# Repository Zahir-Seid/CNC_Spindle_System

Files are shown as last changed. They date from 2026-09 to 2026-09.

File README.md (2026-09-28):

# Design, Analysis and Modeling of CNC Spindle System

Internship project by Group 6, Department of Electromechanical Engineering, AASTU. Host: Ethio-Engineering Group, July–September 2026.

Full report: `Design, Analysis and Modeling of CNC Spindle System.pdf` (source: `.tex`).

## What this project is

Design and system-level model of a BT30 pneumatic tool-change CNC milling spindle rated to 5000 RPM, treated as one integrated mechatronic system: mechanics + motor/drive + PID speed control + PLC supervisory interlock.

Design basis: aluminum 6061-T6 roughing cut with 10 mm 3-flute end mill. Peak cutting force 135 N, peak torque 0.675 N·m, average cutting power ~169 W.

## How it was done

**1. Mechanical design (SolidWorks + hand calcs).**
Shaft, 6004 deep-groove bearings, 7075-T6 housing, BT30-ER20-70 interface, Belleville stack, M12 drawbar, 50:30 5M belt drive, floating puller assembly. Overhung-load model: front bearing 471 N, rear bearing 336 N reversed, max bending moment 16.72 N·m at front bearing.

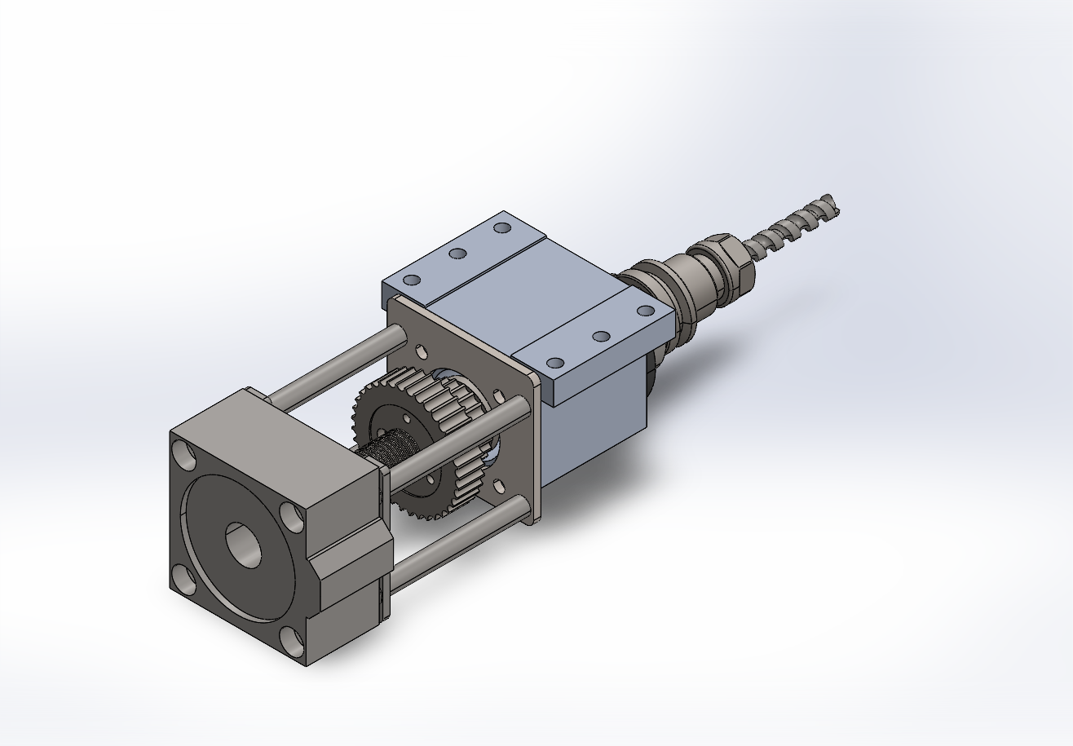
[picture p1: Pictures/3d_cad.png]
CAD assembly


**2. Structural validation (analytical + beam FEA).**
Hollow shaft (20 mm OD / 13 mm ID, 20CrMnTi): von Mises 25.9 MPa, FoS ~28.3. Hand calc and beam FEA agree to 0.1%. Housing shoulder FoS 12–17, puller plate FoS 2.5–3.5. Key finding: shaft is stiffness/bearing-fit governed, not strength governed. Drawbar release load (2940–4021 N) routes through puller plate into housing, bearings stay isolated.

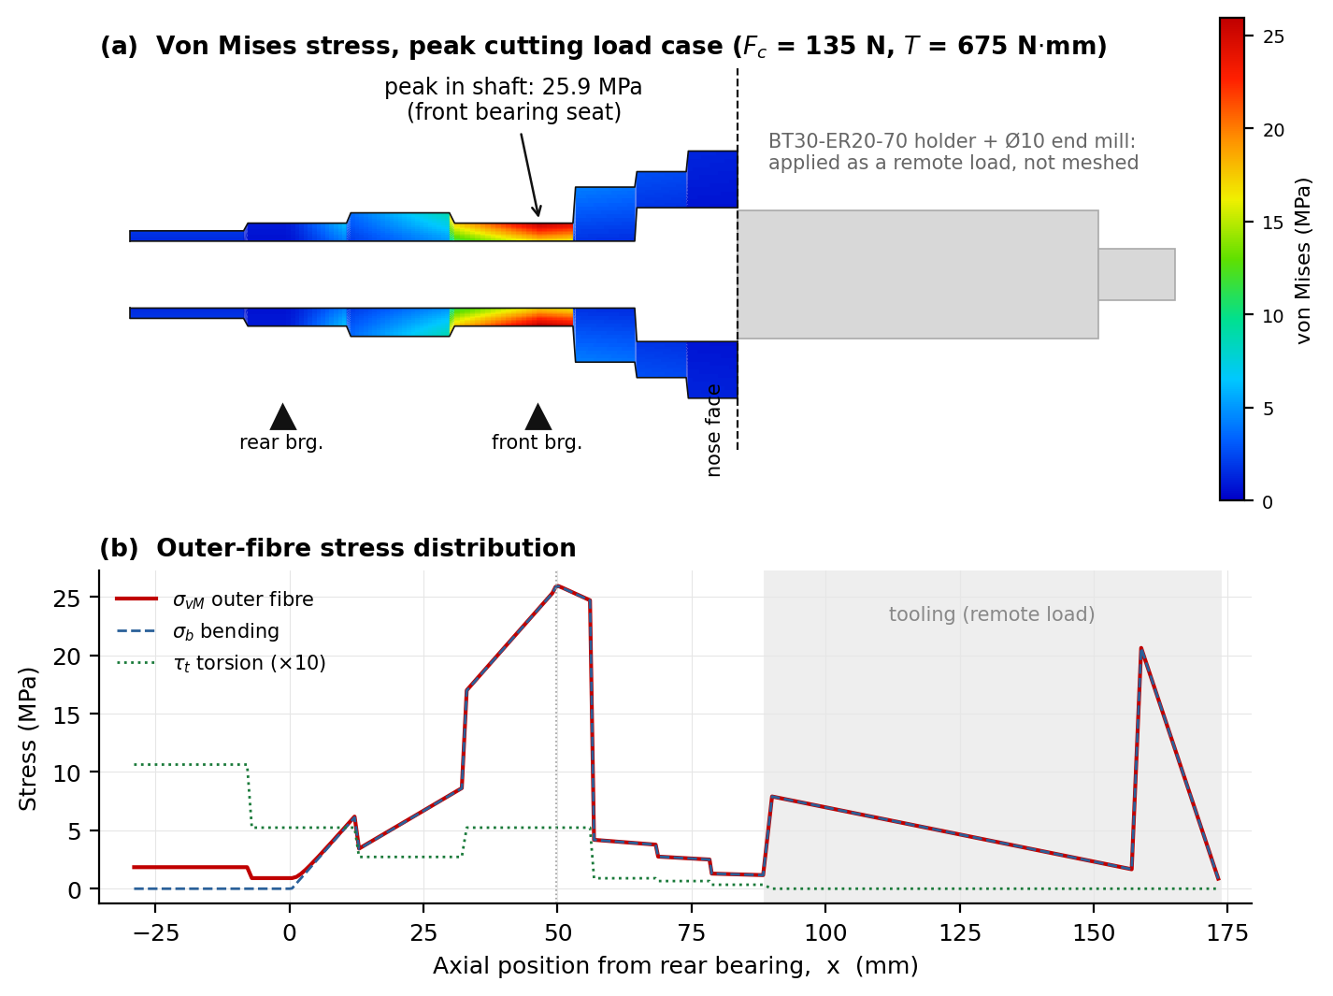
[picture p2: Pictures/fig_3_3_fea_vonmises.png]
FEA von Mises


**3. Electrical drive (AC servo + VFD model).**
1000 W AC servo with brake (220 V variant for 230 V/50 Hz mains), 3000 RPM rated, matches 5000 RPM spindle through exact 5:3 belt ratio. Drive modeled as rectifier – DC link (~310 V) – IGBT inverter with SPWM switching.

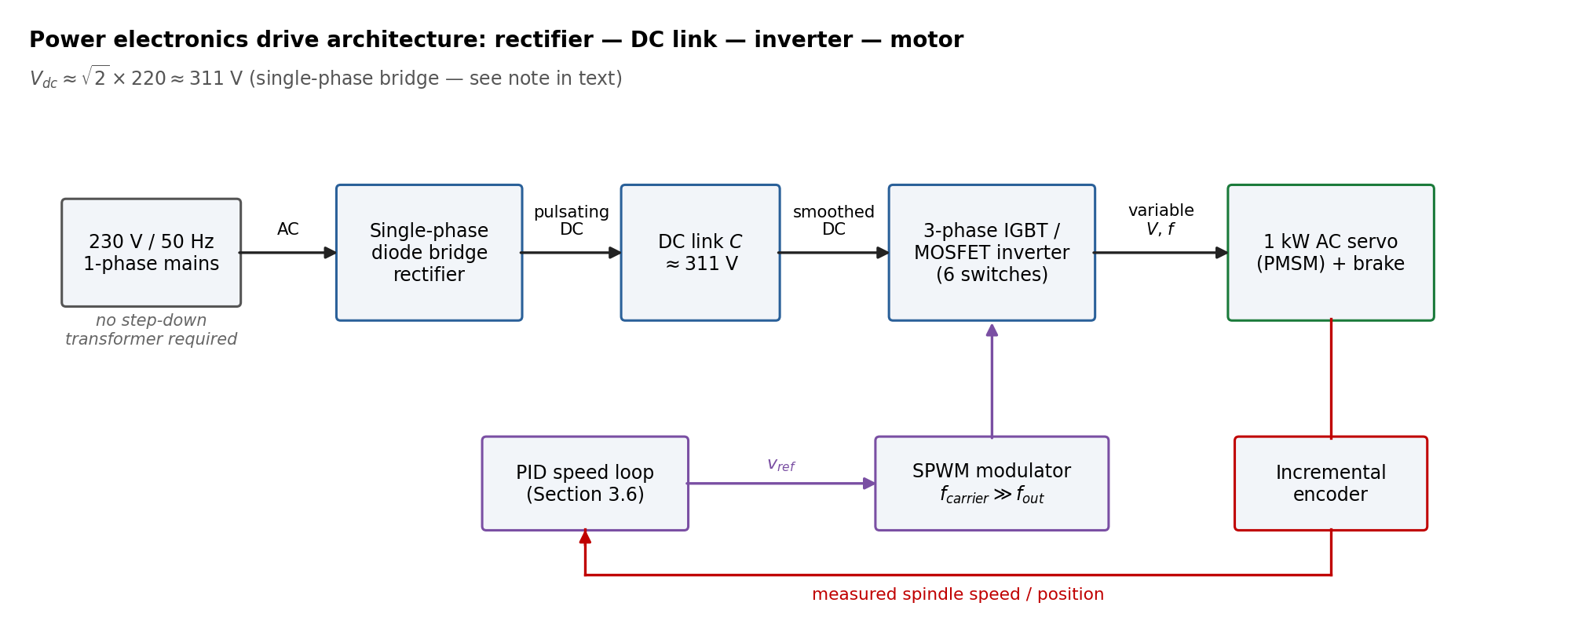
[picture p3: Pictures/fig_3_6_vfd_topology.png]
VFD topology


**4. Control (state-space + PID pole placement, MATLAB).**
Plant: `J dw/dt = Kt·I − B·w − TL`, `L dI/dt = V − R·I − Ke·w`. PID on encoder feedback. Results: 16 ms rise, 26 ms settle, 1.08% overshoot, infinite gain margin, 109 deg phase margin. Peak-torque dip −3.35 rad/s (~0.64%), recovered in ~70–80 ms.

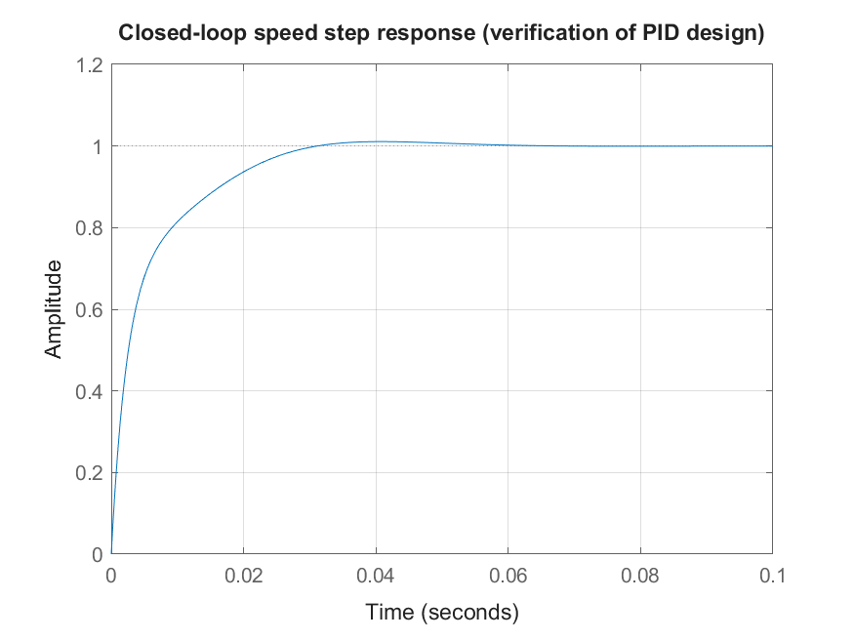
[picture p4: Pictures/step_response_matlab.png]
Step response


**5. Supervisory PLC interlock (Stateflow logic).**
`Cylinder_Actuate = Tool_Request AND (RPM <= 5)`. Without interlock cylinder fires at 5000 RPM. With interlock spindle decelerates first, cylinder fires only at standstill.

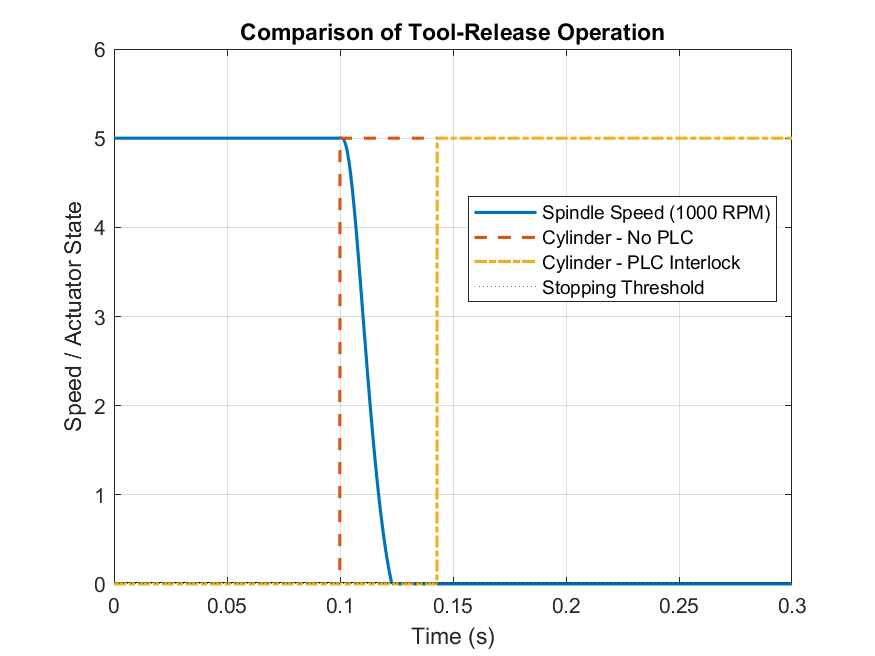
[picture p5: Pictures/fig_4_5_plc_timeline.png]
PLC interlock


## Repository layout

- `Design, Analysis and Modeling of CNC Spindle System.tex/.pdf` — full report
- `Pictures/` — CAD renders, FEA plots, MATLAB figures used above
- `Matlab Scripts/` — PID design script, PLC interlock simulation, Simulink `.slx` drive model
- `3d Models/` — SolidWorks assembly and parts (`.SLDASM/.SLDPRT`)
- `ASSEMBLY_Milling_Spindle_BT30_Drawing.pdf`, `Blockdiagram_simulink.pdf` — drawings and block diagram

To reproduce: open MATLAB scripts in `Matlab Scripts/`, run PID script to regenerate Bode/root-locus/step figures; run PLC script to regenerate interlock timelines; open `.slx` for drive simulation.

## Improvements needed

From Chapter 5 recommendations:

- Replace 6004 deep-groove bearings with angular-contact bearings for thrust capacity; may simplify floating-plate mechanism.
- Extend FEA to transient dynamics with real bearing stiffness: natural frequencies and critical speeds vs 5000 RPM range.
- Add rectifier/inverter loss model to SPWM Simulink model to quantify drive efficiency.
- Extend PLC simulation to full ATC sequence: clamp/unclamp sensors plus ATC arm motion.
- Longer term: IoT remote monitoring, fuzzy/PID hybrid control.

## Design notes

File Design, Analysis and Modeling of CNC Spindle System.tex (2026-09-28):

\documentclass[12pt,a4paper]{report}

% ---------- PACKAGES ----------
\usepackage[a4paper,margin=1in]{geometry}
\usepackage[utf8]{inputenc}
\usepackage[T1]{fontenc}
\usepackage{graphicx}
\graphicspath{{Pictures/}}
\usepackage{amsmath,amssymb}
\usepackage{booktabs}
\usepackage{longtable}
\usepackage{caption}
\usepackage{subcaption}
\usepackage{setspace}
\usepackage{fancyhdr}
\usepackage{xcolor}
\usepackage{listings}
\usepackage{titlesec}
\usepackage{enumitem}
\usepackage{tikz}
\usepackage[hidelinks]{hyperref}
\usepackage{float}                     % provides [H] = "put it HERE, no floating"
\usepackage[section]{placeins}         % \FloatBarrier + auto-barrier at every \section

% ---------- BIBLIOGRAPHY ----------
\renewcommand{\bibname}{References}

% ---------- TIKZ LIBRARIES ----------
\usetikzlibrary{arrows.meta, positioning, fit, backgrounds, shadows.blur, calc}

% ---------- CODE LISTING STYLE (single unified block) ----------
\lstset{
	basicstyle=\ttfamily\footnotesize,
	numbers=left,
	numberstyle=\tiny,
	breaklines=true,
	columns=fullflexible,
	frame=single,
	backgroundcolor=\color{gray!5},
	keywordstyle=\color{blue!70!black},
	commentstyle=\color{green!45!black},
	stringstyle=\color{red!60!black},
	showstringspaces=false,
	tabsize=2,
	language=Matlab
}

% ---------- PAGE STYLE ----------
\onehalfspacing
\pagestyle{fancy}
\fancyhf{}
\fancyhead[R]{\thepage}
\fancyhead[L]{Design, Analysis, and Modeling of a CNC Milling Spindle System}
\renewcommand{\headrulewidth}{0.4pt}

% ---------- TITLE ----------
\title{Design, Analysis, and Modeling of a CNC Milling Spindle System}
\author{}
\date{}

\begin{document}
	
	% =====================================================
	% TITLE PAGE
	% =====================================================
	\begin{titlepage}
		\centering
		
		{\large Addis Ababa Science and Technology University\par}
		{\large Department of Electromechanical Engineering\par}
		
		\vspace{0.8cm}
		
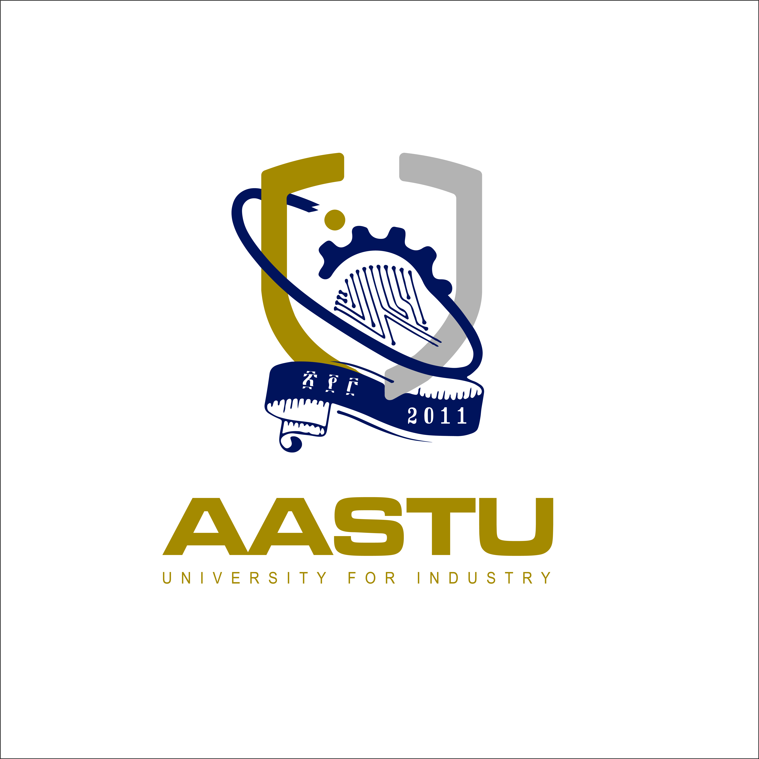
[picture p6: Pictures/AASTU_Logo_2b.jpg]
		
		
		\vspace{0.8cm}
		
		{\Large\bfseries Internship Project\par}
		
		\vspace{0.5cm}
		
		{\Large\bfseries
			Design, Analysis, and Modeling of a CNC Milling Spindle System
			\par}
		
		\vspace{1.5cm}
		
		{\large Submitted by:\par}
		\vspace{0.3cm}
		
		\begin{tabular}{rl}
			1. & Zahir Ahmed \quad ID: ETS1501/15 \\
			2. & Robera Kumsa \quad ID: ETS1162/15 \\
			3. & Samuel Tesfaye \quad ID: ETS1213/15 \\
			4. & Biniam Getahun \quad ID: ETS0350/14 \\
		\end{tabular}
		
		\vspace{1cm}
		
		{\large Submitted to:\par}
		Department of Electromechanical Engineering, AASTU\par
		
		\vspace{0.5cm}
		
		{\large Duration:\par}
		July to September 2026 G.C\par
		
		\vspace{0.5cm}
		
		{\large Organization:\par}
		Ethio-Engineering Group\par
		{\small Addis Ababa, Ethiopia\par}
		
		\vfill
		
		{\large September 15, 2026\par}
		
	\end{titlepage}
	
	% =====================================================
	% ABSTRACT
	% =====================================================
	\begin{abstract}
		This project presents the design, analysis, and modeling of a CNC milling spindle system as an integrated mechatronic system. The spindle is designed for high-speed operation with a maximum target speed of 5000 RPM, requiring consideration of mechanical strength, bearing support, motor selection, variable-speed operation, sensing, and control. The mechanical design includes the spindle shaft, bearing arrangement, housing, mounting components, and tool interface. Computer-aided design is used to develop the spindle assembly, while 
analytical hand calculations and a beam finite-element model are used to evaluate the structural performance of the spindle shaft, complemented by analytical checks of the housing and drawbar hardware.
		
		The electrical and power electronic aspects of the system are incorporated through the selection and modeling of a suitable AC spindle motor and variable frequency drive (VFD). The drive system is represented using an AC-DC-AC architecture consisting of a rectifier, DC link, and three-phase inverter, with pulse width modulation (PWM) used for motor control. A mathematical model of the motor-spindle system is developed based on the rotational dynamics of the system and is used to study the spindle response to speed commands and load disturbances. Closed-loop PID control is implemented using spindle speed feedback to regulate the operating speed.
		
		The automatic tool changer (ATC) and pneumatic drawbar are included as functional components of the overall spindle system. Their detailed mechanical and pneumatic analysis is outside the scope of the project; instead, they are incorporated into the supervisory control sequence. A programmable logic controller (PLC) is modeled as a supervisory layer responsible for sequencing and interlocking the spindle and tool-release operation. In particular, the PLC prevents tool release until the spindle has reached a safe standstill condition. Simulation results are used to evaluate the mechanical performance, motor-spindle dynamic response, PID speed regulation, and PLC-based supervisory interlocking. The project therefore integrates mechanical design, electrical drives, sensors, feedback control, and industrial automation into a unified CNC spindle mechatronic system.
		
		\vspace{0.5cm}
		\noindent\textbf{Keywords:} CNC Spindle, Automatic Tool Changer, Pneumatic Drawbar, Finite Element Analysis (FEA), Variable Frequency Drive (VFD), Pulse Width Modulation (PWM), Sinusoidal Pulse Width Modulation (SPWM), PID Control, PLC Interlocking, Mechatronics
	\end{abstract}
	
	% =====================================================
	% FRONT MATTER
	% =====================================================
	\tableofcontents
	\listoffigures
	\listoftables
	
	% =====================================================
	% CHAPTER 1: INTRODUCTION
	% =====================================================
	\chapter{Introduction}
	
	\section{Background of the Study}
	Computer numerical control (CNC) machine tools are widely used in modern manufacturing because they provide automated and precise control of machining operations. Among the major subsystems of a CNC milling machine, the spindle system is responsible for transmitting rotational power to the cutting tool and maintaining the required cutting speed during machining. The spindle therefore has a direct influence on machining performance, including cutting stability, dimensional accuracy, surface quality, and productivity.
	
	A CNC milling spindle is an electromechanical system in which mechanical, electrical, and control components operate together. Mechanically, the spindle consists of a rotating shaft supported by bearings and connected to a cutting tool. The shaft must withstand the combined effects of torque, bending loads, cutting forces, and rotational effects while maintaining sufficient stiffness and acceptable deformation. Machine-design principles for shafts, bearings, keys, power transmission components, and factors of safety are therefore essential to the spindle design \cite{ref1,ref2,ref3}.
	
	At high rotational speeds, however, static mechanical strength alone is not sufficient to characterize spindle performance. The dynamic behavior of the spindle-bearing system becomes increasingly important. Recent research has demonstrated that spindle speed, bearing stiffness, bearing clearance, imbalance, and other structural parameters can significantly affect spindle vibration and stability. Miao et al. developed a dynamic model of a CNC vertical milling-machine spindle system and showed that spindle speed and bearing parameters influence the vibration characteristics and stability of the system \cite{ref11}. Other studies have similarly investigated the natural frequencies, critical speeds, and imbalance response of high-speed spindle-bearing systems using finite element and dynamic modeling techniques \cite{ref12}.
	
	The spindle also requires a suitable electrical drive system to provide controlled rotational speed. An AC motor combined with a variable frequency drive can provide variable-speed operation by controlling the electrical frequency and voltage supplied to the motor. Electrical-machine theory provides the basis for understanding motor torque, speed, power, and operating characteristics, while power-electronic principles describe the conversion and control of electrical energy through rectifier, DC-link, and inverter stages \cite{ref4,ref5,ref6,ref7,ref8}. Recent work on CNC machining-center spindles has demonstrated the use of VFD-based induction-motor systems together with mathematical modeling and MATLAB/Simulink simulation for spindle speed regulation and load-response analysis \cite{ref13}.
	
	Speed regulation requires feedback and a control system capable of maintaining the desired spindle speed despite changes in operating conditions. A speed sensor such as a rotary encoder provides feedback of the actual spindle speed. The difference between the reference speed and measured speed is then processed by a PID controller to regulate the motor-drive command. Control-system theory provides the basis for analyzing the resulting closed-loop system in terms of stability, transient response, steady-state error, rise time, and settling time \cite{ref9}.
	
	In addition to continuous speed control, CNC equipment requires discrete supervisory functions to coordinate machine operations. Automatic tool changing is one such operation. The spindle must be brought to a suitable condition before the tool-release mechanism is activated. PLC-based control provides a practical method for implementing such sequencing and interlocking functions. Previous research has demonstrated the use of PLCs for CNC machine automation and tool-changing operations, including the coordination of machine inputs, outputs, and tool-change sequences \cite{ref14,ref15}.
	
	Therefore, the spindle considered in this project is treated as an integrated mechatronic system rather than as an isolated mechanical component. The mechanical structure, electrical drive, speed feedback, PID controller, and PLC supervisory logic are considered together. The design is based on a commercially available BT30 pneumatic tool-change spindle platform, which is modeled in CAD and analyzed across the mechanical, electrical, control, and automation domains. The primary design and analytical emphasis remains on the mechanical spindle, while the electrical, control, and automation subsystems are modeled at a level appropriate for demonstrating their interaction within the complete system.
	
	\section{Problem Statement}
	The spindle is one of the most important functional components of a CNC milling machine because it directly determines the rotational speed and power available to the cutting tool. Designing a spindle for high-speed operation requires more than selecting a rotating shaft. The shaft, bearings, housing, motor, drive system, sensors, and control system must operate together while maintaining acceptable mechanical and dynamic performance.
	
	A mechanically adequate spindle may still experience poor performance if its motor-drive system cannot provide the required speed or if the control system cannot maintain the desired speed under changing cutting loads. Similarly, a speed controller alone cannot guarantee safe tool-changing operation. A tool-release command issued while the spindle is still rotating can result in an unsafe operating condition. Consequently, continuous speed regulation and discrete machine sequencing must be considered as separate but coordinated control functions.
	
	Previous research has addressed different aspects of CNC spindle systems, including spindle-bearing dynamics, finite element modeling, motor-drive control, and PLC-based automation. For example, dynamic spindle studies have investigated the influence of bearing characteristics and spindle speed on vibration behavior \cite{ref11}, while VFD-based spindle research has demonstrated mathematical and MATLAB/Simulink models for speed control of AC motor-driven CNC spindles \cite{ref13}. PLC-based research has also demonstrated the use of programmable controllers for CNC automation and tool-change operations \cite{ref14,ref15}. These functions are, however, frequently treated in isolation from one another.
	
	The problem addressed in this project is therefore the design and system-level modeling of a CNC milling spindle that combines the mechanical spindle structure with an electrical drive, speed feedback, PID control, and PLC-based supervisory interlocking. The project demonstrates how these subsystems operate together within a single, coherent mechatronic system.
	
	\section{Objectives}
	\subsection{General Objective}
	To design, analyze, and model a CNC milling spindle system as an integrated mechatronic system incorporating mechanical design, electrical drive modeling, PID speed control, sensing, and PLC-based supervisory interlocking.
	
	\subsection{Specific Objectives}
	The specific objectives of the project are to:
	\begin{enumerate}[label=\arabic*.]
		\item Design the main mechanical components of a CNC milling spindle capable of operating at a target maximum speed of 5000 RPM.
		\item Determine the required spindle torque, power, shaft dimensions, and bearing loads based on the specified operating and cutting conditions.
		\item Develop a three-dimensional CAD model and assembly of the spindle system using SolidWorks.
		\item Analyze the mechanical behavior of the spindle components using analytical calculations and finite element analysis.
		\item Evaluate spindle stress, deformation, and factor of safety under the specified loading conditions.
		\item Select and model a suitable AC spindle motor and variable frequency drive for the required operating speed.
		\item Develop a mathematical model representing the rotational dynamics of the motor-spindle system.
		\item Develop a representation of the power-electronic drive, including the rectifier, DC link, inverter, and PWM-based switching.
		\item Develop a closed-loop PID speed-control system using spindle speed feedback.
		\item Evaluate the dynamic response of the spindle under speed commands and load disturbances.
		\item Develop a PLC-based supervisory sequence for spindle stopping and tool-release operation.
		\item Implement an interlocking condition that prevents pneumatic drawbar activation until the spindle reaches the required safe-speed condition ($\leq 5$~RPM).
		\item Compare the simulated spindle/tool-release behavior with and without PLC supervisory interlocking.
		\item Demonstrate the integration of mechanical, electrical, sensing, control, and automation subsystems within the CNC spindle system.
	\end{enumerate}
	
	\section{Scope and Limitation}
	The project covers the design, analysis, and system-level modeling of a CNC milling spindle intended for operation up to 5000 RPM. The mechanical scope includes the spindle shaft, bearing arrangement, housing and mounting components, tool interface, and the other major structural components required for the spindle assembly. CAD modeling is performed using SolidWorks, while analytical calculations and FEA are used to evaluate the mechanical performance of the design.
	
	The electrical scope covers the selection and functional modeling of an AC motor and variable frequency drive. The drive is represented at the system level using the conventional rectifier, DC-link, and inverter structure. PWM, particularly sinusoidal PWM, is the modulation method used by the inverter to control the motor supply. The project does not include detailed semiconductor-device design, thermal analysis of IGBTs, detailed electromagnetic design of the motor, or physical construction of a VFD.
	
	The control scope includes mathematical modeling of the motor-spindle dynamics and closed-loop PID speed control. A speed-feedback sensor provides the measured spindle speed to the controller. The performance of the controller is evaluated using simulated speed commands and load disturbances.
	
	The automatic tool changer and pneumatic drawbar are treated as functional components of the overall CNC spindle system. They are not subjected to detailed mechanical, pneumatic, fluid-dynamic, or manufacturing analysis. Instead, the pneumatic drawbar is represented as a simplified actuator in the supervisory-control model, and its operation is coordinated by the PLC according to the spindle operating state.
	
	The PLC component of the project is modeled at the supervisory level. The PLC is responsible for sequencing and interlocking operations, while the PID controller provides continuous spindle-speed regulation. The PLC handles discrete logic for operations such as spindle stopping, safe-speed verification, and tool-release permission. The project does not involve the construction of a complete industrial PLC control panel or physical implementation of the automatic tool changer.
	
	\section{Methodology Overview}
	The methodology begins with the identification of the main operating requirements of the CNC milling spindle, including the target rotational speed, mechanical loading conditions, required torque, and power requirements. These requirements establish the initial dimensions and configuration of the spindle system.
	
	The mechanical design is developed through analytical calculations based on established machine-design and mechanics principles. Shaft loading is evaluated under bending and torsional conditions, while bearing loads and other relevant mechanical requirements are determined from the specified operating conditions. The resulting geometry is developed as a three-dimensional CAD assembly in SolidWorks.
	
	Finite element analysis is subsequently performed on the critical mechanical components. The FEA model evaluates stress and deformation under the defined loading conditions. The analytical and numerical results are compared to confirm that the design satisfies the required structural conditions.
	
	The electrical subsystem is developed by selecting a spindle motor and representing its connection to a variable frequency drive. The drive is modeled using a functional AC-DC-AC architecture consisting of a rectifier, DC link, and inverter. PWM represents the generation of controlled switching signals for motor operation. The electrical and mechanical subsystems are combined to form a mathematical model of the motor-spindle system.
	
	A closed-loop speed controller is developed using PID control. The reference spindle speed is compared with the measured speed, and the resulting error is processed by the controller to generate the motor-drive command. The model is simulated to evaluate speed tracking, transient response, steady-state error, and response to changes in load torque.
	
	Finally, a supervisory PLC model is developed to coordinate the spindle and tool-release sequence. When a tool-release request is received, the PLC first commands the spindle to stop and verifies that the spindle has reached the defined safe-speed condition. Only after this condition is satisfied is the pneumatic drawbar permitted to activate. The resulting behavior is compared with a system without PLC interlocking to demonstrate the effect of supervisory control on safe tool-release operation.
	
	The overall methodology can therefore be represented as:
	
	\begin{figure}[htbp]
		\centering
		\begin{tikzpicture}[
			node distance=6mm and 6mm,
			every node/.style={font=\footnotesize\sffamily},
			step/.style={
				rectangle, rounded corners=4pt,
				draw=#1!60!black, fill=#1!10,
				line width=0.8pt, inner sep=4pt,
				minimum height=8mm, text width=22mm,
				align=center, font=\footnotesize\bfseries
			},
			terminal/.style={
				step=#1, rounded corners=10pt, text width=24mm
			},
			arrow/.style={
				-{Stealth[length=2mm,width=1.6mm]},
				line width=0.9pt, draw=gray!65
			},
			phaselabel/.style={
				font=\scriptsize\bfseries\sffamily, text=#1
			}
			]
			
			% Row 1
			\node[terminal=blue!70!black] (dr)  {Design\\Requirements};
			\node[step=blue!70!black, right=of dr] (md) {Mechanical\\Design};
			\node[step=blue!70!black, right=of md] (cad){CAD\\Modeling};
			
			% Row 2
			\node[step=orange!80!black, below=12mm of cad] (aa) {Analytical\\Analysis};
			\node[step=orange!80!black, left=of aa]          (fea){FEA};
			
			% Row 3
			\node[step=violet!80!black, below=12mm of fea] (mdm){Motor/Drive\\Modeling};
			\node[step=violet!80!black, right=of mdm]      (mm) {Mathematical\\Modeling};
			\node[step=violet!80!black, right=of mm]       (pid){PID\\Control};
			\node[step=violet!80!black, right=of pid]      (plc){PLC Supervisory\\Logic};
			
			% Row 4
			\node[step=teal!70!black, below=12mm of plc] (is){Integrated\\Simulation};
			\node[terminal=teal!70!black, left=of is]    (rc){Results \&\\Comparison};
			
			% Arrows
			\draw[arrow] (dr)  -- (md);
			\draw[arrow] (md)  -- (cad);
			\draw[arrow] (cad) -- (aa);
			\draw[arrow] (aa)  -- (fea);
			\draw[arrow] (fea) -- (mdm);
			\draw[arrow] (mdm) -- (mm);
			\draw[arrow] (mm)  -- (pid);
			\draw[arrow] (pid) -- (plc);
			\draw[arrow] (plc) -- (is);
			\draw[arrow] (is)  -- (rc);
			
			% Phase backgrounds
			\begin{scope}[on background layer]
				\node[fit=(dr)(md)(cad), fill=blue!5, draw=blue!40,
				rounded corners=6pt, inner sep=6pt,
				label={[phaselabel=blue!70!black]above:Phase 1 --- Requirements \& Design}] {};
				\node[fit=(aa)(fea), fill=orange!5, draw=orange!40,
				rounded corners=6pt, inner sep=6pt,
				label={[phaselabel=orange!80!black]above:Phase 2 --- Analysis \& Verification}] {};
				\node[fit=(mdm)(mm)(pid)(plc), fill=violet!5, draw=violet!40,
				rounded corners=6pt, inner sep=6pt,
				label={[phaselabel=violet!80!black]above:Phase 3 --- Actuation \& Control}] {};
				\node[fit=(is)(rc), fill=teal!5, draw=teal!40,
				rounded corners=6pt, inner sep=6pt,
				label={[phaselabel=teal!70!black]above:Phase 4 --- Integration \& Validation}] {};
			\end{scope}
			
		\end{tikzpicture}
		\caption{Overall methodology: from design requirements to validated results.}
		\label{fig:methodology}
	\end{figure}
	
	% =====================================================
	% CHAPTER 2: LITERATURE REVIEW
	% =====================================================
	\chapter{Literature Review}
	
	\section{Spindle Mechanics and Bearing Dynamics}
	The spindle is a critical rotating subsystem of a CNC milling machine because it transmits mechanical power from the drive system to the cutting tool while maintaining the required rotational speed and positional stability. Its mechanical design must provide adequate strength and stiffness while limiting deformation and vibration during operation. The design of shafts, bearings, keys, power-transmission components, and supporting structures is established using standard machine-design and mechanics principles \cite{ref1,ref2,ref3}.
	
	For a spindle shaft, the applied loading is a combination of torsional and bending loading. The transmitted motor torque produces torsional stress, while cutting forces acting at the tool produce bending moments. The combined loading is considered when determining the shaft dimensions and evaluating the resulting factor of safety. The shaft must also maintain sufficient stiffness so that excessive deflection does not affect the position of the cutting tool.
	
	Bearing selection is equally important because the bearings support the rotating spindle while transmitting radial and axial loads to the housing. At high rotational speeds, bearing stiffness, preload, clearance, and dynamic behavior influence the overall response of the spindle. Consequently, bearing selection is considered together with spindle geometry and operating speed.
	
	Recent research has demonstrated the importance of considering spindle and bearing dynamics together. Miao et al. developed a dynamic model of a CNC vertical milling-machine spindle system incorporating nonlinear bearing restoring forces, radial clearance, and time-varying bearing stiffness \cite{ref11}. Their results showed that spindle speed and bearing parameters influence the vibration characteristics and stability of the spindle system. The study also considered factors such as pulley eccentricity, tool overhang, and bearing arrangement, demonstrating the interaction between spindle configuration and dynamic behavior.
	
	Other research has used finite element models to investigate the vibration characteristics of high-speed spindle-bearing systems. Such studies have examined natural frequencies, mode shapes, critical speeds, and unbalanced response, with bearing stiffness identified as an important factor in the dynamic characteristics of the spindle \cite{ref12}. These findings indicate that the spindle is evaluated not only according to static strength requirements but also according to its dynamic operating characteristics.
	
	A dynamic model of a spindle-bearing system has also been developed using finite element representation of the spindle shaft and tool-holder assembly. The model considered the interaction between the spindle shaft, bearings, housing, and cutting forces and was used to investigate frequency-response and time-domain behavior under different spindle speeds and cutting conditions \cite{ref16}. The agreement between simulated and experimental responses demonstrated the usefulness of dynamic spindle models for evaluating machine-tool performance.
	
	For the present project, these studies establish the importance of integrating shaft design, bearing support, loading, and dynamic behavior into a single design process, which is the approach adopted in Chapter 3.
	
	\section{Electrical Drives in Machining}
	The spindle motor and its associated drive form the electrical portion of the spindle system. Unlike a conventional fixed-speed motor application, a CNC spindle requires controlled variation of rotational speed according to the machining operation. Electrical-machine theory provides the basis for selecting an appropriate motor, while power-electronic drives provide the means of controlling the voltage and frequency supplied to the motor \cite{ref4,ref5,ref6,ref7,ref8}.
	
	AC motors are widely applicable to industrial variable-speed drive systems because of their robustness and compatibility with electronic power conversion. For an induction motor, the synchronous speed is related to the electrical supply frequency and the number of motor poles by
	\begin{equation}
		N_s=\frac{120f}{P}
	\end{equation}
	where $N_s$ is the synchronous speed in revolutions per minute, $f$ is the electrical supply frequency, and $P$ is the number of poles. The actual rotor speed differs from synchronous speed because of slip \cite{ref4,ref5,ref6}. This relationship makes frequency control the primary method for variable-speed operation of induction-motor-driven systems. The present project uses a permanent-magnet synchronous (PMSM/BLDC-family) AC servo motor instead, discussed in Section~\ref{sec:machine_selection}; the synchronous-speed relationship above still governs the inverter's output-frequency requirement.
	
	A variable frequency drive provides the required electrical conversion and control. A conventional AC drive is represented by an AC-DC-AC structure consisting of a rectifier, DC link, and inverter. The rectifier converts the input AC supply into DC, the DC link smooths and stores electrical energy, and the inverter generates a controlled output for the motor. Power-electronic switching devices such as IGBTs are controlled using PWM techniques to synthesize the required output voltage waveform \cite{ref7,ref8}.
	
	PWM provides a practical method of controlling the inverter output by rapidly switching the power devices. In sinusoidal PWM, a sinusoidal reference waveform is compared with a high-frequency carrier signal to generate the switching pulses. The frequency of the reference signal is associated with the desired motor electrical frequency, while the modulation index influences the output voltage magnitude. More advanced approaches, including space-vector PWM and vector control, have also been extensively investigated for AC motor drives.
	
	Recent research has directly applied VFD-based control to CNC machining-center spindles. A recent study developed a rotational model of a CNC spindle incorporating an AC motor, transmission system, and rotating spindle, and developed an induction-motor model in the $d$-$q$ reference frame. The resulting VFD-based system was implemented and evaluated using MATLAB/Simulink under speed commands and torque-load disturbances \cite{ref13}. The study demonstrates the suitability of mathematical and simulation-based approaches for analyzing variable-speed CNC spindle drives.
	
	PLC-based spindle drive systems have also been investigated in high-speed machine applications. Yin et al. developed a high-speed spindle drive-control system using a PLC, frequency converter, speed feedback sensor, and PID closed-loop control. The system used spindle-speed feedback to regulate the motor speed and employed the PLC for real-time signal acquisition and system control \cite{ref17}.
	
	These studies support the use of an AC motor, VFD, speed sensor, and closed-loop controller in the present project, and the system described in Chapter 3 follows this architecture.
	
	\section{Machining Dynamics and Control}
	The spindle operates under continuously changing mechanical conditions during machining. Changes in cutting conditions modify the torque required from the motor, causing variations in spindle speed if the drive system is unable to compensate for the disturbance. For this reason, mathematical modeling and closed-loop speed control are essential parts of an integrated spindle system.
	
	The mechanical behavior of the spindle is represented by a rotational dynamic equation:
	\begin{equation}
		J\frac{d\omega}{dt}=T_m-T_L-B\omega
	\end{equation}
	where $J$ represents the equivalent rotational inertia of the motor-spindle system, $\omega$ represents angular velocity, $T_m$ is the motor torque, $T_L$ is the external load torque, and $B$ represents the equivalent viscous damping coefficient. This model provides a representation of the relationship between motor torque, mechanical loading, and spindle speed.
	
	The mathematical model is incorporated into a feedback-control system. In closed-loop speed control, the desired spindle speed is compared with the measured spindle speed. The difference between these values forms the control error. A PID controller processes this error and produces a control command for the motor-drive system \cite{ref9}.
	
	The PID controller is represented by
	\begin{equation}
		u(t)=K_pe(t)+K_i\int e(t)\,dt+K_d\frac{de(t)}{dt}
	\end{equation}
	where $e(t)$ is the speed error, $K_p$ is the proportional gain, $K_i$ is the integral gain, and $K_d$ is the derivative gain. The proportional term responds to the magnitude of the current error, the integral term eliminates persistent steady-state error, and the derivative term responds to changes in the error.
	
	Recent research has emphasized the importance of dynamic modeling in CNC spindle systems. Miao et al. developed a detailed spindle dynamic model and examined its behavior under different spindle speeds, bearing parameters, imbalance conditions, and tool configurations \cite{ref11}. Their work demonstrates that spindle dynamics significantly affect machining stability and accuracy. Another recent spindle-modeling study used a system-level modeling approach to investigate spindle dynamics and energy behavior, demonstrating the usefulness of simulation models for studying the response of spindle systems under different operating conditions.
	
	Speed-control research has also demonstrated the use of feedback controllers with spindle drive systems. In the VFD-based CNC spindle study discussed above, a closed-loop controller was used to regulate spindle speed and evaluate the dynamic response of the spindle under torque disturbances \cite{ref13}. Experimental work on high-speed spindle drive systems has similarly combined frequency converters, speed feedback, PLC control, and PID-based closed-loop regulation to maintain the required spindle speed \cite{ref17}.
	
	In the present project, PID control is therefore used as the \textbf{continuous control layer} responsible for maintaining the desired spindle speed. The PLC does not replace this controller. Instead, it provides a separate \textbf{supervisory control layer} for discrete operations and safety interlocking. This distinction is important because speed regulation and tool-change sequencing represent different types of control problems.
	
	During tool release, for example, the PID controller regulates the spindle at its commanded speed while having no knowledge of whether a tool-release operation is safe. A PLC supervisory controller monitors the tool-release request and spindle-speed feedback, commands the spindle to stop, verifies the spindle speed is below the 5~RPM safety threshold, and only then permits the pneumatic drawbar to activate. Research on CNC tool-changing has demonstrated the use of PLC programming to coordinate automated tool-change operations in CNC machine systems \cite{ref14}, while other CNC automation research has demonstrated PLC-based coordination of machine inputs, outputs, motor control, and automatic loading and unloading \cite{ref15}.
	
	The proposed control architecture therefore combines continuous PID speed regulation with discrete PLC supervisory logic. This provides a complete representation of the CNC spindle as a mechatronic system rather than treating the mechanical spindle, motor drive, and automation functions as independent systems.
	
	% =====================================================
	% CHAPTER 3: SYSTEM DESIGN
	% =====================================================
	\chapter{System Design}
	
	\section{Mechanical Design}\label{sec:mech_design}
	This section follows the standard machine-design sequence: establish the design loads
	(Section~\ref{sec:load_analysis}), select and size each machine element against those loads
	(Sections~\ref{sec:machine_elements}--\ref{sec:shaft_design}), and describe how the assembly is realized
	(Section~\ref{sec:fab_assembly}). The design is based on a commercially available BT30
	pneumatic tool-change spindle platform, modeled in SolidWorks and analyzed below.
	
	\subsection{Load Analysis}\label{sec:load_analysis}
	
	\subsubsection{Design Cutting Scenario}\label{sec:baseline_cutting}
	The design loads for the shaft, bearings, and drive motor are established from a roughing
	scenario using Aluminum 6061-T6 as the workpiece material and a 10~mm diameter, 3-flute
	solid carbide end mill. Aluminum represents a realistic roughing condition for a
	light-industrial BT30 spindle and remains within the load capacity of the deep-groove
	bearings and the 5M timing belt drive. The design parameters are:
	
	\begin{itemize}
		\item Workpiece material: Aluminum 6061-T6
		\item Tool: $\varnothing 10$~mm solid carbide end mill, $z = 3$ flutes
		\item Spindle speed: $N = 5000$~RPM (rated maximum)
		\item Feed per tooth: $f_z = 0.05$~mm/tooth
		\item Axial depth of cut: $a_p = 3.0$~mm
		\item Radial depth of cut: $a_e = 5.0$~mm (50\% radial engagement)
	\end{itemize}
	
	The specific cutting force is taken as $k_c = 900$~N/mm$^2$, at the upper end of the
	range reported for 6061-T6 in machining handbooks (typically 600--800~N/mm$^2$). Using
	the conservative figure biases every downstream force, stress, bearing life, and shaft
	dimension on the safe side.
	
	Cutting speed and feed rate follow directly:
	\begin{align}
		V_c &= \frac{\pi D N}{1000} = \frac{\pi (10)(5000)}{1000} \approx 157.1~\text{m/min} \\
		v_f &= f_z \, z \, N = (0.05)(3)(5000) = 750~\text{mm/min}
	\end{align}
	
	\subsubsection{Material Removal Rate and Average Cutting Power}\label{sec:mrr_power}
	The material removal rate is:
	\begin{equation}
		\text{MRR} = a_p \, a_e \, v_f = (3)(5)(750) = 11{,}250~\text{mm}^3\text{/min} = 187.5~\text{mm}^3\text{/s}
	\end{equation}
	Taking $k_c = 900$~N/mm$^2$ and converting to specific cutting energy
	$u = k_c / 1000 = 0.9$~J/mm$^3$, the average cutting power at the spindle is:
	\begin{equation}
		P_{c,avg} = u \cdot \text{MRR} = (0.9)(187.5) \approx 169~\text{W}
	\end{equation}
	This average power figure is the basis for continuous motor power sizing (Section~\ref{sec:motor_sizing}).
	
	\subsubsection{Peak Cutting Force and Spindle Torque (Torsion)}\label{sec:peak_force_torque}
	Average power alone understates the instantaneous structural load, since milling is an
	intermittent process. Using a simplified Kienzle-type model with $h \approx f_z$, the peak
	tangential force on a single engaged tooth is:
	\begin{equation}
		F_{c,peak} = k_c \, a_p \, f_z = (900)(3)(0.05) = 135~\text{N}
	\end{equation}
	The tooth engagement angle for $a_e/D = 50\%$ is $\phi_{a_e} = \arccos(1 - 2a_e/D) = 90^\circ$,
	compared to a tooth pitch angle of $360^\circ/z = 120^\circ$. Since $\phi_{a_e} < 360^\circ/z$,
	only one tooth is engaged at any instant, confirming an intermittent, single-tooth worst-case
	loading condition. The corresponding peak spindle torque (the shaft's \emph{torsional} load)
	is:
	\begin{equation}
		T_{peak} = F_{c,peak} \cdot \frac{D}{2} = (135)(0.005) = 0.675~\text{N}\cdot\text{m}
	\end{equation}
	
	\subsubsection{Overhung Load, Bending, and Bearing Reactions}\label{sec:overhung_bending}
	The end mill acts at the end of a cantilevered overhang beyond the front (nose) bearing, so
	$F_{c,peak}$ also produces a \emph{bending} load on the shaft, and amplifies the radial load
	seen by each bearing beyond the applied cutting force itself -- this is the standard
	overhung-load model used in bearing catalogs \cite{ref1}. Modeling the shaft as simply
	supported between the front and rear bearings (span $L_1$) with the tool tip overhanging the
	front bearing by $L_2$: $L_1 = 49.7$~mm is the point-to-point distance between the front and
	rear bearing-seat shoulder centers, measured directly from the CAD geometry and verified
	against an independent axis-to-axis cross-check. The overhang $L_2 = 123.85$~mm combines a
	38.85~mm nose-to-front-bearing distance with the tool holder's own projection. The tool
	holder is a \textbf{BT30-ER20-70} with a 70~mm gauge-length projection, plus an additional
	15~mm allowance for the 10~mm end mill's stick-out beyond the collet face. Since the
	tool holder is a physically separate component whose body sits almost entirely outside the
	housing (protruding from the spindle nose), its full projection is additive to the
	housing-side measurement:
	$L_2 = 38.85 + 70 + 15 = 123.85$~mm. The bearing reactions and peak bending moment are:
	\begin{align}
		R_{front} &= F_{c,peak}\cdot\frac{L_1+L_2}{L_1} = 135 \times \frac{173.55}{49.7} \approx 471.4~\text{N} \\
		R_{rear} &= F_{c,peak}\cdot\frac{L_2}{L_1} = 135 \times \frac{123.85}{49.7} \approx 336.4~\text{N} \quad (\text{reversed direction}) \\
		M_{max} &= F_{c,peak}\cdot L_2 = 135 \times 123.85 \approx 16{,}720~\text{N}\cdot\text{mm} = 16.72~\text{N}\cdot\text{m} \quad (\text{at the front bearing})
	\end{align}
	Two points follow directly: (i) the front bearing radial load is more than triple the applied
	cutting force purely due to the overhang geometry, and (ii) the rear bearing reaction
	\emph{reverses direction} relative to the applied load -- deep-groove ball bearings tolerate
	this radial reversal without issue. These values feed directly into the bearing
	life check (Section~\ref{sec:bearing_design}) and the shaft diameter calculation (Section~\ref{sec:shaft_design}).
	
	\begin{figure}[H]
		\centering
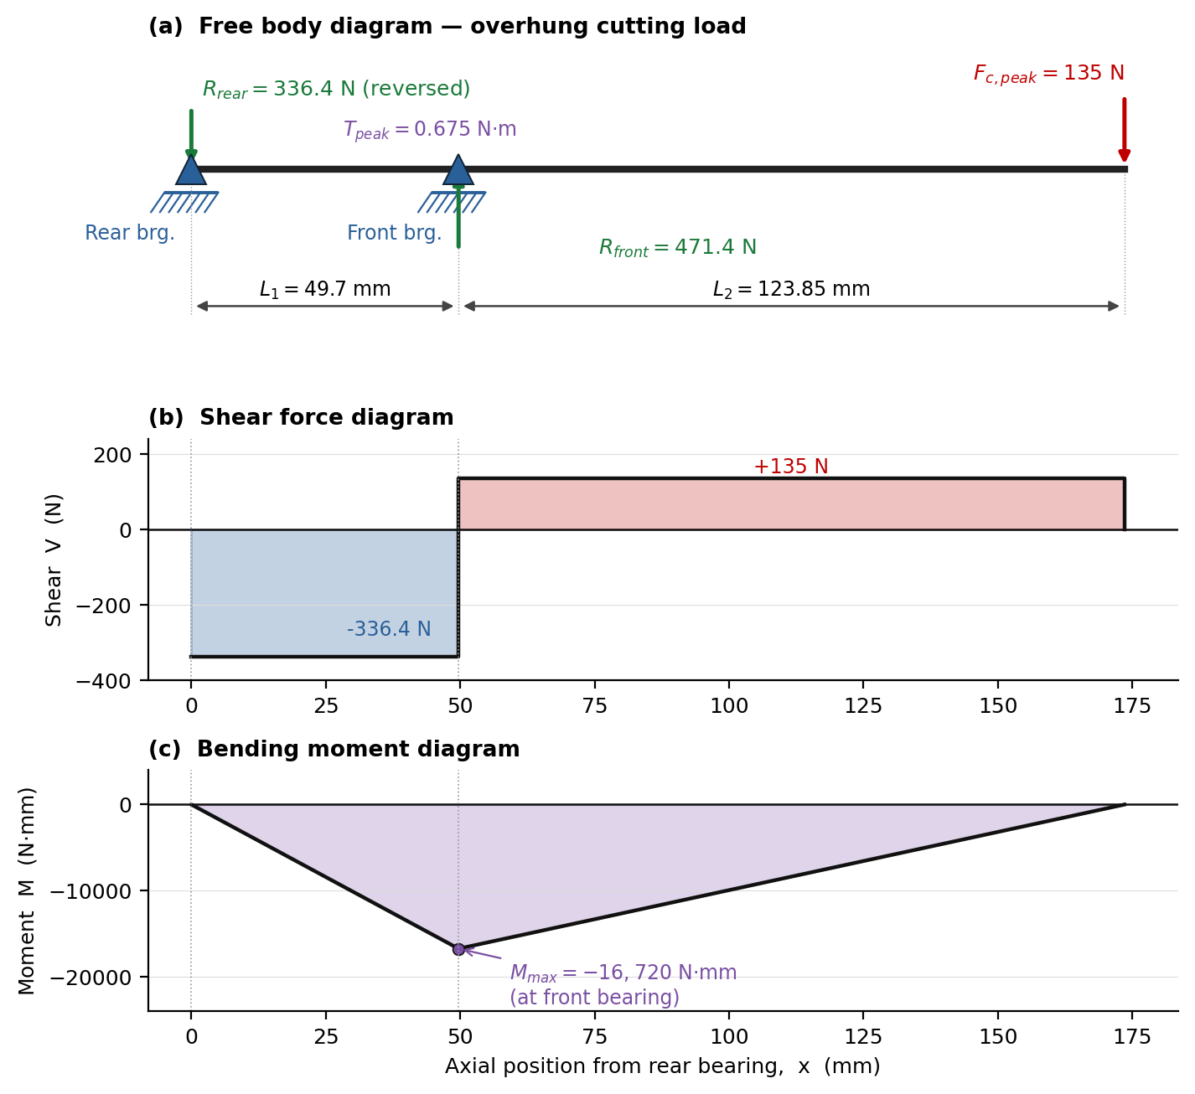
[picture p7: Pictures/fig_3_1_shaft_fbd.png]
		
		\caption{Overhung-load free body diagram and shear/bending-moment diagram for the spindle shaft.}
		\label{fig:shaft_fbd}
	\end{figure}
	
	\subsubsection{Pneumatic Drawbar Axial Load}\label{sec:drawbar_load}
	The tool-change (drawbar release) event applies a separate, large axial load through the
	spindle centerline, unrelated to the cutting load above. The actuator is a pneumatic
	cylinder rated to deliver $F_{cyl} = 2940$~N (300~kgf) at a supply pressure of
	$0.8$~MPa \cite{ref1}. The theoretical force from the bore area alone
	($A = \pi D_{bore}^2/4 = \pi(80)^2/4 = 5026.5$~mm$^2$) is:
	\begin{equation}
		F_{cyl,max} = P \cdot A = (0.8)(5026.5) \approx 4021~\text{N}
	\end{equation}
	The ratio $F_{cyl}/F_{cyl,max} = 2940/4021 \approx 0.731$ is consistent with typical
	pneumatic-cylinder mechanical efficiency of 70--75\% once seal friction and internal flow
	losses are accounted for; the manufacturer's rated force is the \emph{net} output after
	those losses, while the bore-area calculation gives the theoretical maximum. The design
	drawbar load case used in Sections~\ref{sec:machine_elements} and \ref{sec:bearing_design} is
	therefore bracketed between $2940$~N (rated, realistic) and $4021$~N (theoretical maximum,
	worst case).
	
	\subsubsection{Motor Power and Torque Requirement}\label{sec:motor_sizing}
	Sizing the drive motor requires converting spindle-side average power/torque to the motor
	side across the 5M timing belt (sized in Section~\ref{sec:belt_pulley}). The manufacturer's
	product specification for the pulley pair gives a motor pulley of 50 teeth and a spindle
	pulley of 30 teeth -- the \emph{motor} pulley is larger, so the motor runs \emph{slower}
	than the spindle, a step-up ratio of $50/30 = 5/3 \approx 1.667\!:\!1$ (spindle:motor).
	The direction of the ratio is confirmed by the motor's rated speed: a 1~kW-class AC servo
	is near-universally rated at $\sim$3000~RPM, and $5000 \times 30/50 = 3000$~RPM matches
	that exactly. The reverse direction (30~T motor, 50~T spindle) would require the motor to
	run at 8333~RPM to reach the spindle's rated 5000~RPM, which no motor in this class can
	do -- so the 50:30 configuration is the only one physically consistent with the specified
	hardware.
	
	With a belt efficiency of $\eta = 0.90$ and a service factor of $SF = 1.5$ (tool wear,
	chip evacuation, roughing dynamics):
	\begin{equation}
		P_{motor} \geq \frac{P_{c,avg}}{\eta}\times SF = \frac{169}{0.90}\times 1.5 \approx 281~\text{W}
	\end{equation}
	A motor rated at 300--400~W (continuous) is therefore sufficient for the aluminum-roughing
	scenario alone. The spindle kit is equipped with a \textbf{1000~W AC servo motor with
		brake}, providing a substantial margin that covers steel and heavier cuts beyond the
	aluminum baseline analyzed here. The motor is specified in its \textbf{220~V} input-rated
	variant, matching Ethiopia's 230~V/50~Hz single-phase mains standard directly with no
	step-down transformer required (Section~\ref{sec:machine_selection} discusses this further). At 1000~W the motor
	is sized at $3.5\times$ the calculated minimum, and its rated 3000~RPM speed coincides
	precisely with the spindle's top operating speed through the 5:3 belt ratio.
	
	\subsection{Design of Machine Elements}\label{sec:machine_elements}
	This section covers the principal load-carrying and functional elements of the spindle: the
	housing and tool interface, the Belleville washer stack, the drawbar and pull stud, the
	retention hardware, the spindle key, and the floating puller assembly. Standard fasteners
	that are selected by standard practice are not individually calculated here; the elements
	below are the ones that govern performance, safety, or accuracy.
	
	\paragraph{Spindle housing and tool interface.} The housing is 7075-T6 aluminum,
	selected for its high strength-to-weight ratio relative to 6061, which reduces
	rotating/reciprocating mass without a proportional cost increase for a low-volume build.
	The BT30 taper with ER20 collet is a fixed interface dictated by the spindle platform.
	ER20 covers a 1--13~mm clamping range, which accommodates the 10~mm end mill used in the
	design scenario (Section~\ref{sec:load_analysis}).
	
	\paragraph{Belleville washer stack.} Disc (Belleville) springs are used in place of a
	conventional coil spring because the drawbar must generate a large clamping force over a
	very short axial travel (a few millimeters) within the tight radial envelope of the spindle
	bore -- Belleville washers have the highest force-per-unit-volume of the common spring types
	and are the standard solution for this application \cite{ref1}. Stacking washers
	\emph{in parallel} (same orientation) increases the delivered force for a given deflection;
	stacking \emph{in series} (alternating orientation) increases deflection at a given force.
	The stack is configured to deliver the clamping force required to resist tool pull-out under
	the peak cutting force computed in Section~\ref{sec:peak_force_torque}.
	
	\paragraph{Drawbar and pull stud.} The pull stud threads into the tool holder's retention
	knob per the BT30 standard and is pulled rearward by the Belleville stack to seat the taper.
	The M12 pull stud is the standard size for this tooling class.
	
	\paragraph{Retention hardware.} The drawbar is retained by an M8 lock screw and locknut,
	reacting a shear load equal to the drawbar force via $\tau = F/A_{shear}$ with
	$A_{shear} = \pi d_{minor}^2/4$ \cite{ref1}. For M8 ($d_{minor} = 6.647$~mm,
	$A_{shear} = 34.71$~mm$^2$):
	
	\begin{table}[htbp]
		\centering
		\caption{Shear stress and factor of safety in the M8 drawbar retention hardware.}
		\label{tab:retention_hardware}
		\begin{tabular}{lccc}
			\toprule
			Condition & Axial Force (N) & Shear Stress $\tau$ (MPa) & Factor of Safety \\
			\midrule
			Rated ($F_{cyl}$) & 2940 & 84.7 & 2.18 \\
			Theoretical maximum ($F_{cyl,max}$) & 4021 & 115.9 & 1.60 \\
			\bottomrule
		\end{tabular}
	\end{table}
	
	\noindent Against a typical allowable shear stress of
	$\tau_{allow} \approx 0.577\,S_y \approx 185$~MPa for a common-grade fastener \cite{ref1},
	the M8 retention hardware clears both load cases with margin.
	
	\paragraph{Spindle key.} A 5~mm $\times$ 30~mm parallel key is used on the shaft, sized per
	standard key tables for a $\sim$20~mm shaft (Section~\ref{sec:shaft_design}). Checking it
	against the peak torque from Section~\ref{sec:peak_force_torque} ($T_{peak} = 675$~N$\cdot$mm)
	with key width $b=5$~mm, height $h=5$~mm, length $L=30$~mm, and shaft radius $r=10$~mm \cite{ref1}:
	\begin{align}
		\tau_{key} &= \frac{T_{peak}}{b\,L\,r} = \frac{675}{(5)(30)(10)} = 0.45~\text{MPa} \\
		\sigma_{bearing} &= \frac{2\,T_{peak}}{h\,L\,r} = \frac{2(675)}{(5)(30)(10)} = 0.9~\text{MPa}
	\end{align}
	Both are trivial compared to a typical key-stock allowable ($\tau_{allow} \sim 100$~MPa).
	The key's function is therefore \emph{not} torque capacity -- it is
	\textbf{eliminating slip} so that the encoder's measured position tracks the true spindle
	position, which is a requirement for the closed-loop control in Section~\ref{sec:controller_design}.
	
	\paragraph{Floating puller assembly.} The pneumatic cylinder drives a puller plate along two
	guide rods, compressing the return springs. The load is transferred through the puller rod
	into a bearing tube that houses a bearing, allowing the non-rotating puller rod to press
	axially on the rotating drawbar and pull disc without transmitting rotation into the
	stationary actuation hardware. A lower plate is the fixed reaction structure: it carries the
	axial release force directly into the housing, isolating the spindle bearings from the
	drawbar release load. A flanged bolt and lower stop set the stroke and prevent
	over-extension of the mechanism, and a load-spreading washer distributes the cylinder
	mounting load.

	\subsection{Belt and Pulley Design}\label{sec:belt_pulley}
	The 5M (5~mm pitch) HTD timing belt drive uses 50 teeth on the (slower) motor pulley and
	30 teeth on the (faster) spindle pulley, per the manufacturer's product specification. The
	pitch diameters are:
	\begin{equation}
		PD = \frac{Z \cdot p}{\pi} \;\Rightarrow\; PD_{motor} = \frac{(50)(5)}{\pi} \approx 79.6~\text{mm}, \qquad
		PD_{spindle} = \frac{(30)(5)}{\pi} \approx 47.7~\text{mm}
	\end{equation}
	The tangential belt force required to transmit the peak spindle torque (Section~\ref{sec:peak_force_torque}) is:
	\begin{equation}
		F_t = \frac{T_{peak}}{PD_{spindle}/2} = \frac{675}{23.9} \approx 28.3~\text{N}
	\end{equation}
	which is well within the rated capacity of a standard 5M belt at this width. The belt
	width and pitch are confirmed against the pulley manufacturer's power-rating table for the
	50:30 tooth combination.
	
	\subsection{Bearing Design}\label{sec:bearing_design}
	Two load cases act on the spindle: the radial cutting load, which is carried by the spindle
	bearings, and the axial drawbar release load, which is reacted by the floating puller plate
	and the housing rather than by the spindle bearings (Section~\ref{sec:machine_elements}).
	Accordingly, the bearings are sized on the radial cutting load, while the axial drawbar load
	is checked against the housing shoulder and the puller plate.
	
	The confirmed shaft diameter class ($\sim$19--20~mm, cross-checked against multiple
	independent CAD measurements) specifies a 20~mm-bore deep-groove ball bearing. The
	\textbf{6004 (20$\times$42$\times$12~mm)} series is selected, with catalog ratings
	(consistent across SKF, FAG, NSK, Schaeffler) of $C_r \approx 9.95$~kN and
	$C_{0r}\approx5.0$~kN.
	
	\paragraph{Radial (dynamic/fatigue) check -- cutting load.} Using the overhung-load front
	bearing reaction $R_{front} = 471.4$~N (Section~\ref{sec:overhung_bending}):
	\begin{equation}
		L_{10} = \left(\frac{C_r}{R_{front}}\right)^3 = \left(\frac{9950}{471.4}\right)^3 \approx 9{,}405 \times 10^6~\text{rev}
		\;\Rightarrow\;
		L_{10h} = \frac{10^6}{60N}\left(\frac{C_r}{R_{front}}\right)^3 \approx 31{,}350~\text{hours}
	\end{equation}
	The rear bearing carries a lower (and reversed-direction) reaction of $336.4$~N and therefore
	has a longer calculated life; the reversal itself is not a concern for deep-groove bearings,
	which handle bidirectional radial load without issue. 

Fatigue life is clearly not the
	governing concern for this bearing under the light aluminum-roughing load. Belt-tension loading is secondary to the overhung cutting force and is not separately included in the fatigue estimate, which is therefore conservative. Belt-tension loading is secondary to the overhung cutting force and is not separately included in the fatigue estimate, which is therefore conservative.
	
	\paragraph{Supporting check -- housing shoulder.} As a cross-check that the
	7075-T6 \emph{housing structure itself} is not independently overstressed, the average
	compressive (bearing) stress was evaluated at the smallest real annular shoulder area
	measured directly from the housing geometry ($A = 97.4$~mm$^2$, at the step nearest the front
	bearing seat):
	\begin{equation}
		\sigma_{shoulder} = \frac{F_{cyl}}{A} = \frac{2940}{97.4} \approx 30.2~\text{MPa (rated)}, \qquad
		\frac{4021}{97.4} \approx 41.3~\text{MPa (theoretical max.)}
	\end{equation}
	Against 7075-T6's yield strength ($S_y\approx503$~MPa), this gives FoS $\approx 12$--$17$ --
	the aluminum housing comfortably survives simple compressive contact.
	
	\subsection{Shaft Design}\label{sec:shaft_design}
	The shaft carries both the bending moment from the overhung cutting load and the torsional
	load from cutting torque simultaneously, so it is sized against the \emph{combined} stress
	state rather than either load alone. The shaft material is \textbf{20CrMnTi}, a
	low-carbon case-hardening (carburizing) steel, consistent with the manufacturer's
	specification of an ultra-high hardness heat treatment and full grinding, which describes a
	carburized-and-ground surface. Its near-identical European equivalent \textbf{20MnCr5} (same
	low-carbon Cr-Mn carburizing family) gives well-documented post-quench-and-temper core
	properties of $S_u \approx 930$~MPa and $S_y \approx 735$~MPa, which are used here as the
	design basis. Because this is a case-hardened steel, two separate design checks apply: the
	bulk combined-stress check below uses the \emph{core} properties, while the case hardness
	($\sim$58--60~HRC, typical for this family) resists wear specifically at the bearing seats
	and keyway flank.
	
	The shaft is bored through its full length to pass the M12 drawbar and Belleville washer
	stack (Section~\ref{sec:machine_elements}); the bore diameter through the bearing-seat region
	is 13~mm. This is not a minor detail: a hollow section has a smaller section modulus than a
	solid section of the same outer diameter, so the combined-stress check below is carried out
	for the actual hollow section, not a solid-shaft approximation.
	
	As a first-pass sizing check, the ASME shaft design equation for a rotating solid shaft under
	combined bending and torsion with minor shock loading ($C_b = 1.5$, $C_t = 1.0$) \cite{ref1}
	gives a lower-bound solid-equivalent diameter:
	\begin{equation}
		d^3 = \frac{16}{\pi\,\tau_{allow}}\sqrt{(C_b M_{max})^2 + (C_t T_{peak})^2}
	\end{equation}
	Using $M_{max} = 16{,}720$~N$\cdot$mm and $T_{peak} = 675$~N$\cdot$mm from Section~\ref{sec:load_analysis}, with
	$\tau_{allow} = \min(0.18S_u, 0.3S_y) = \min(167.4, 220.5) = 167.4$~MPa, further reduced
	by a 25\% stress-concentration allowance for the keyway per ASME code convention
	($\tau_{allow,eff} \approx 125.6$~MPa):
	\begin{equation}
		d^3 = \frac{16}{\pi(125.6)}\sqrt{(1.5\times16{,}720)^2 + (1.0\times675)^2} \approx 1017~\text{mm}^3
		\;\Rightarrow\; d_{min} \approx 10.06~\text{mm}
	\end{equation}
	The shaft outer diameter at the bearing seats is $d=20$~mm, matched to the 6004 bearing bore
	(Section~\ref{sec:bearing_design}) -- just under $2\times$ this solid-equivalent minimum.
	
	Evaluating the combined (von Mises) stress for the \emph{actual hollow} section
	($d_o=20$~mm, $d_i=13$~mm) at this location:
	\begin{align}
		I &= \frac{\pi(d_o^4-d_i^4)}{64} = \frac{\pi(20^4-13^4)}{64} \approx 6452~\text{mm}^4, \qquad
		J = 2I \approx 12{,}904~\text{mm}^4 \\
		\sigma_b &= \frac{M_{max}\,(d_o/2)}{I} = \frac{16{,}720(10)}{6452} \approx 25.9~\text{MPa}, \qquad
		\tau_t = \frac{T_{peak}\,(d_o/2)}{J} = \frac{675(10)}{12{,}904} \approx 0.52~\text{MPa} \\
		\sigma_{vm} &= \sqrt{\sigma_b^2 + 3\tau_t^2} \approx 25.9~\text{MPa} \quad\Rightarrow\quad \text{FoS} = S_y/\sigma_{vm} \approx 28.3
	\end{align}
	This hand-calculated result matches an independent beam finite-element model
	(Section~\ref{sec:discussion}) to within rounding (25.9~MPa vs.\ 25.93~MPa, FoS~28.3 in both
	cases) -- a genuine, unforced agreement between two different calculation methods, since the
	FE model was built from the same measured geometry and loads but solved independently
	element-by-element rather than with a single closed-form section check.
	
	This confirms that the shaft is \textbf{stiffness/bearing-fit governed, not strength
		governed}: even the hollow section carries roughly 28 times the margin needed against yield
	for this cutting load. This is a common and expected outcome for a light-duty spindle and is
	stated explicitly in the discussion (Section~\ref{sec:discussion}). The nominal-stress result is a
	lower bound -- it does not capture local stress concentration at the keyway root or fillet
	radii (typically $K_t\approx1.5$--$2$), which the beam finite-element study in Section~\ref{sec:fea}
	resolves; even applying $K_t=2$ directly, however, the result ($\approx$51.8~MPa) remains
	well below the 125.6~MPa allowable.
	
	\subsection{Fabrication and Assembly}\label{sec:fab_assembly}
	The design combines commercial off-the-shelf (COTS) components with a small number of
	custom-machined or modified parts:
	\begin{itemize}
		\item \textbf{COTS:} deep-groove ball bearings, Belleville washers, pneumatic cylinder
		and fittings, 5M timing belt and stock pulleys, BT30-ER20 collet holder, M8 hardware.
		\item \textbf{Custom/modified:} the puller plate, pull disc, and lower plate
		(CNC-milled flat stock); the shaft keyway (broached or wire-EDM slot cut into the shaft
		and pulley bore); and the drawbar-top cap carrying the M8 retention hardware.
	\end{itemize}
	Assembly proceeds as: (1) press-fit bearings into the housing; (2) install the keyed shaft
	and pulley; (3) set the Belleville stack preload via the M8 lock screw and nut; (4) fit the
	floating assembly (guide rods, return springs, puller plate, bearing tube, pull disc) above
	the housing; (5) mount and align the pneumatic cylinder; (6) verify BT30 taper runout against
	the 0.02~mm design tolerance, which cross-checks against the FEA deflection result
	in Section~\ref{sec:fea}.
	
	\section{CAD Modeling}\label{sec:cad_modeling}
	The complete spindle assembly is modeled in SolidWorks, incorporating the spindle shaft,
	the bearing arrangement, the housing, the tool interface, the Belleville washer stack, the
	drawbar and pull stud, the retention hardware, the keyed pulley coupling, and the floating
	puller assembly. The CAD model provides the geometry used throughout the load analysis in
	Section~\ref{sec:load_analysis}, including the bearing span, the overhang length, the pulley tooth
	counts, the shoulder areas, and the mass properties required for the rotational dynamics
	model in Section~\ref{sec:math_modeling}.
	
\begin{figure}[htbp]
	\centering
	
	\caption{BT30 spindle/drawbar assembly, modeled in SolidWorks.}
	\label{fig:cad_assembly}
\end{figure}
	
	\section{Mechanical Design Analysis}\label{sec:fea}
	The design is validated against both governing load cases -- the peak cutting load
	(Section~\ref{sec:peak_force_torque}) and the drawbar release load
	(Section~\ref{sec:drawbar_load}) -- using a beam finite-element model of the spindle shaft
	that complements the analytical hand calculations of Section~\ref{sec:shaft_design}. The
	two methods agree to within 0.1\% on the peak bending stress, confirming both the
	analytical result and the numerical implementation.
	
	\subsection*{Material Properties and Setup}
	\begin{table}[H]
		\centering
		\caption{Material properties used in the analysis.}
		\label{tab:fea_materials}
		\begin{tabular}{lll}
			\toprule
			Component & Material & Key Properties \\
			\midrule
			Spindle housing & 7075-T6 Aluminum Alloy & $S_y \approx 503$~MPa, $E \approx 71.7$~GPa \\
			Floating plates & 7075-T6 Plate & $S_y \approx 460$~MPa, $E \approx 71.7$~GPa \\
			Spindle shaft & 20CrMnTi (core) & $S_y \approx 735$~MPa, $S_u \approx 930$~MPa, $E \approx 200$~GPa \\
			\bottomrule
		\end{tabular}
	\end{table}
	
	The beam model applies the front and rear bearing seats as transverse simple supports and
	the cutting force $F_{c,peak} = 135$~N as a point load at the tool tip
	(Section~\ref{sec:overhung_bending}), reproducing the overhung-load configuration derived
	analytically. The drawbar axial load $F_{cyl} = 2940$--$4021$~N (Section~\ref{sec:drawbar_load})
	is evaluated analytically through the load path of the floating puller assembly, since it
	does not load the shaft itself.
	
	\begin{figure}[H]
		\centering
		
		\caption{Beam finite-element result: bending stress distribution under the peak cutting
			load case. Peak bending stress occurs at the front bearing seat, matching the
			closed-form calculation of Section~\ref{sec:shaft_design}.}
		\label{fig:fea_vonmises}
	\end{figure}
	
	\begin{figure}[H]
		\centering
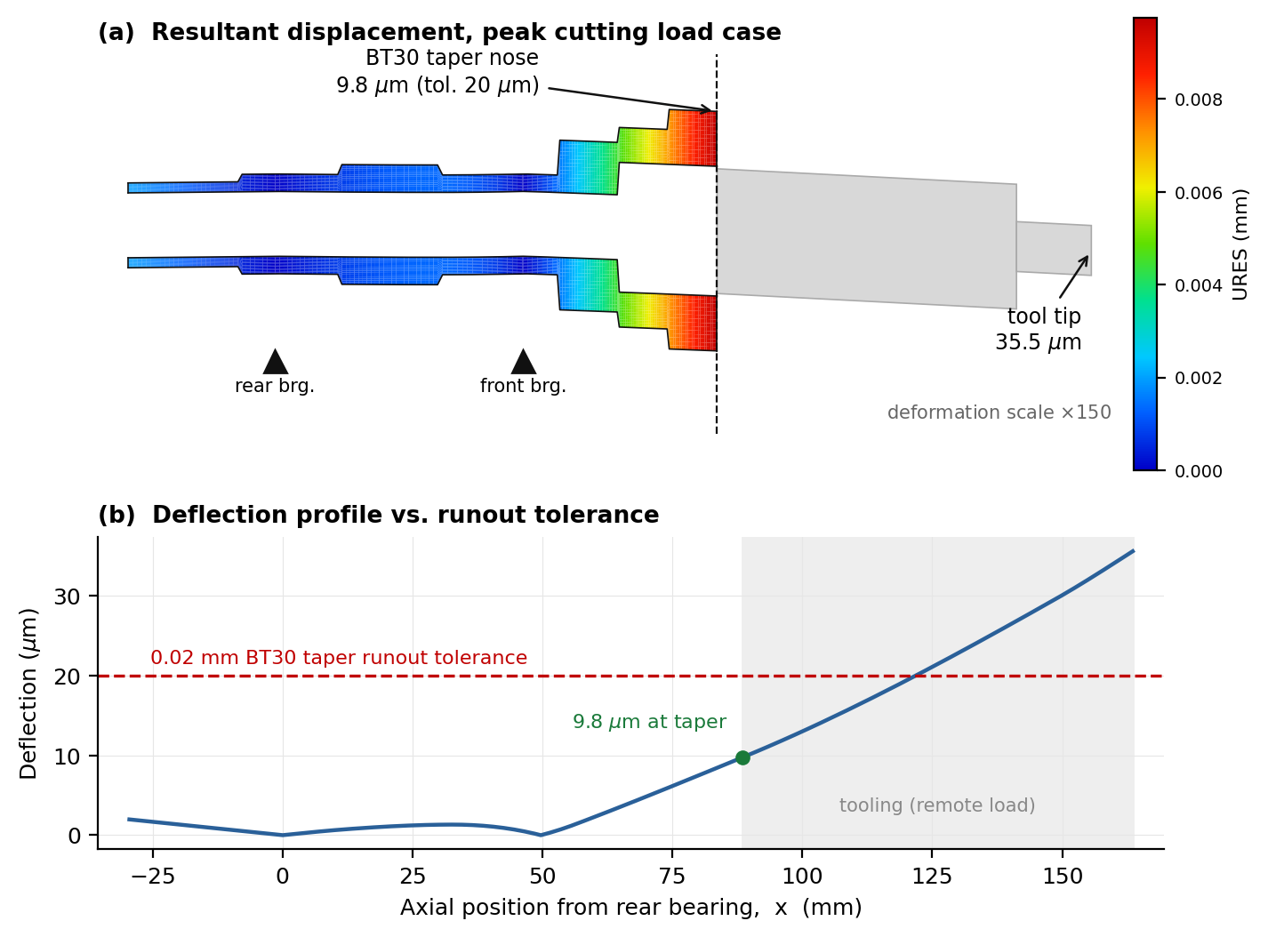
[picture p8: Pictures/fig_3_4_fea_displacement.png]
		
		\caption{Beam finite-element result: transverse deflection along the shaft, checked
			against the 0.02~mm runout tolerance at the BT30 taper.}
		\label{fig:fea_deformation}
	\end{figure}
	
	\begin{table}[H]
		\centering
		\caption{Mechanical analysis results summary for each load case.}
		\label{tab:fea_results}
		\begin{tabular}{lcccc}
			\toprule
			Load Case & Component & Max.\ Stress & Max.\ Deflection & FoS \\
			\midrule
			Cutting load & Shaft & 25.9~MPa & 0.044~mm & 28.3 \\
			Drawbar load & Housing shoulder & 30.2--41.3~MPa & --- & 12.2--16.7 \\
			Drawbar load & Puller plate & 132--181~MPa & --- & 2.5--3.5 \\
			\bottomrule
		\end{tabular}
	\end{table}
	
	The results confirm that the design satisfies every structural requirement. The spindle
	shaft is stiffness-governed rather than strength-governed: the 25.9~MPa peak bending stress
	is more than an order of magnitude below the 735~MPa yield strength of the 20CrMnTi core,
	so the 20~mm shaft diameter is set by the 6004 bearing bore and stiffness requirements, not
	by strength. The housing shoulder carries the drawbar load at 30.2--41.3~MPa against the
	7075-T6 yield strength of 503~MPa, a safety factor of 12.2--16.7. The puller plate carries
	the full release load with a safety factor of at least 2.5. Together these results confirm
	the design's central structural argument: the floating puller-plate assembly routes the
	drawbar release load directly into the housing, keeping the spindle bearings fully isolated
	from the axial release shock.
	
	\section{Electrical \& Power Electronic System Design}
	
	\subsection{Electrical Machine Selection}\label{sec:machine_selection}
	An AC induction motor and a brushless DC (BLDC)/PMSM machine were both considered for
	driving the spindle. AC induction machines are robust and low-cost but require
	slip-dependent speed estimation for closed-loop control \cite{ref4}; BLDC/PMSM machines offer
	a linear torque-speed relationship and pair naturally with the rotary encoder feedback
	required for the keyed-pulley closed-loop control described in Section~3.6, at a higher
	component cost \cite{ref8}. The spindle kit is equipped with a \textbf{1000~W AC servo
		motor with brake}, available in both 110~V and 220~V input-rated variants. An AC servo
	uses a permanent-magnet synchronous (BLDC-family) rotor internally but is packaged and
	driven as a servo axis, and it satisfies the encoder-feedback requirement directly since
	servo motors are supplied with integrated position feedback as standard. Its power rating
	($3.5\times$ the calculated minimum from Section~\ref{sec:motor_sizing}) and its standard
	$\sim$3000~RPM rated speed (which, combined with the measured 5:3 belt ratio, lines up
	with the spindle's rated 5000~RPM \emph{exactly} -- Section~\ref{sec:motor_sizing}) are both
	consistent with this design, and the integrated \textbf{brake} is a safety feature for the
	supervisory logic in Section~\ref{sec:plc_logic}, since it can hold the spindle at zero speed during a tool
	change independent of motor torque control.
	
	\paragraph{Regional power compatibility.}
	Ethiopia's electrical grid standard is 230~V
	single-phase / 380~V three-phase at 50~Hz \cite{ref18}, consistent with the majority of
	50~Hz-standard countries worldwide. The \textbf{220~V input-rated variant} of the
	servo/drive is specified for this reason, matching the local mains voltage directly with no
	step-down transformer required. The supply frequency (50~Hz vs.\ the 60~Hz common in some
	other markets) is not a design concern for this motor: the servo drive rectifies incoming AC
	to an internal DC bus before inverting it to the motor's own commanded frequency
	(Section~\ref{sec:vfd_arch}), so line frequency does not propagate through to the motor as it would for a
	simple across-the-line induction motor.
	
	\begin{figure}[htbp]
		\centering
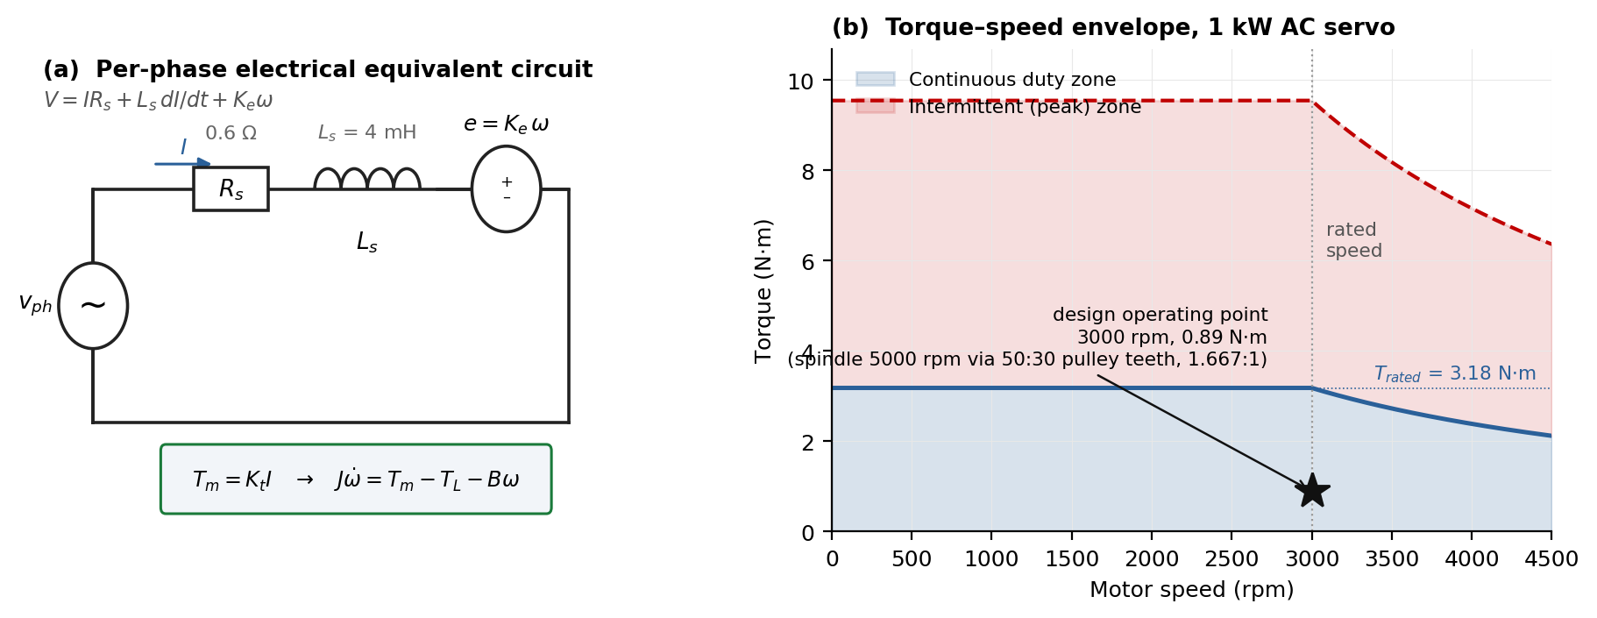
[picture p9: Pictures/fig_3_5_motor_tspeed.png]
		
		\caption{AC servo motor equivalent circuit and torque-speed curve.}
		\label{fig:motor_tspeed}
	\end{figure}
	
	\subsection{Power Electronics Drive Architecture}\label{sec:vfd_arch}
	The drive stage follows the standard AC--DC--AC (VFD/servo drive) topology: a single-phase
	diode bridge rectifier converts the 230~V line AC to unregulated DC, a DC-link capacitor
	smooths this bus voltage, and a 3-phase IGBT (or MOSFET, at this power level) bridge
	inverter synthesizes a variable-frequency, variable-voltage 3-phase output to the motor
	\cite{ref5,ref6,ref7}. The rectifier stage is single-phase because the 220~V servo variant
	specified in Section~3.4.1 is a single-phase-input product; the inverter output remains
	3-phase because the PMSM motor itself has three stator windings, independent of how many
	phases feed the rectifier.
	
	\begin{figure}[h]
		\centering
		
		\caption{Power electronics drive architecture: rectifier -- DC link -- inverter -- motor.}
		\label{fig:vfd_topology}
	\end{figure}
	
	\subsection{PWM Generation Strategy}\label{sec:pwm}
	Sinusoidal Pulse-Width Modulation (SPWM) is used to synthesize the variable-frequency AC
	output: a high-frequency triangular carrier is compared against a lower-frequency sinusoidal
	reference (whose frequency and amplitude are set by the speed command), and the IGBT
	switching states are determined by the intersection of the two waveforms \cite{ref7}. The
	resulting pulse train, once filtered by the motor winding inductance, produces a
	near-sinusoidal phase current at the commanded frequency.
	
	\begin{figure}[h]
		\centering
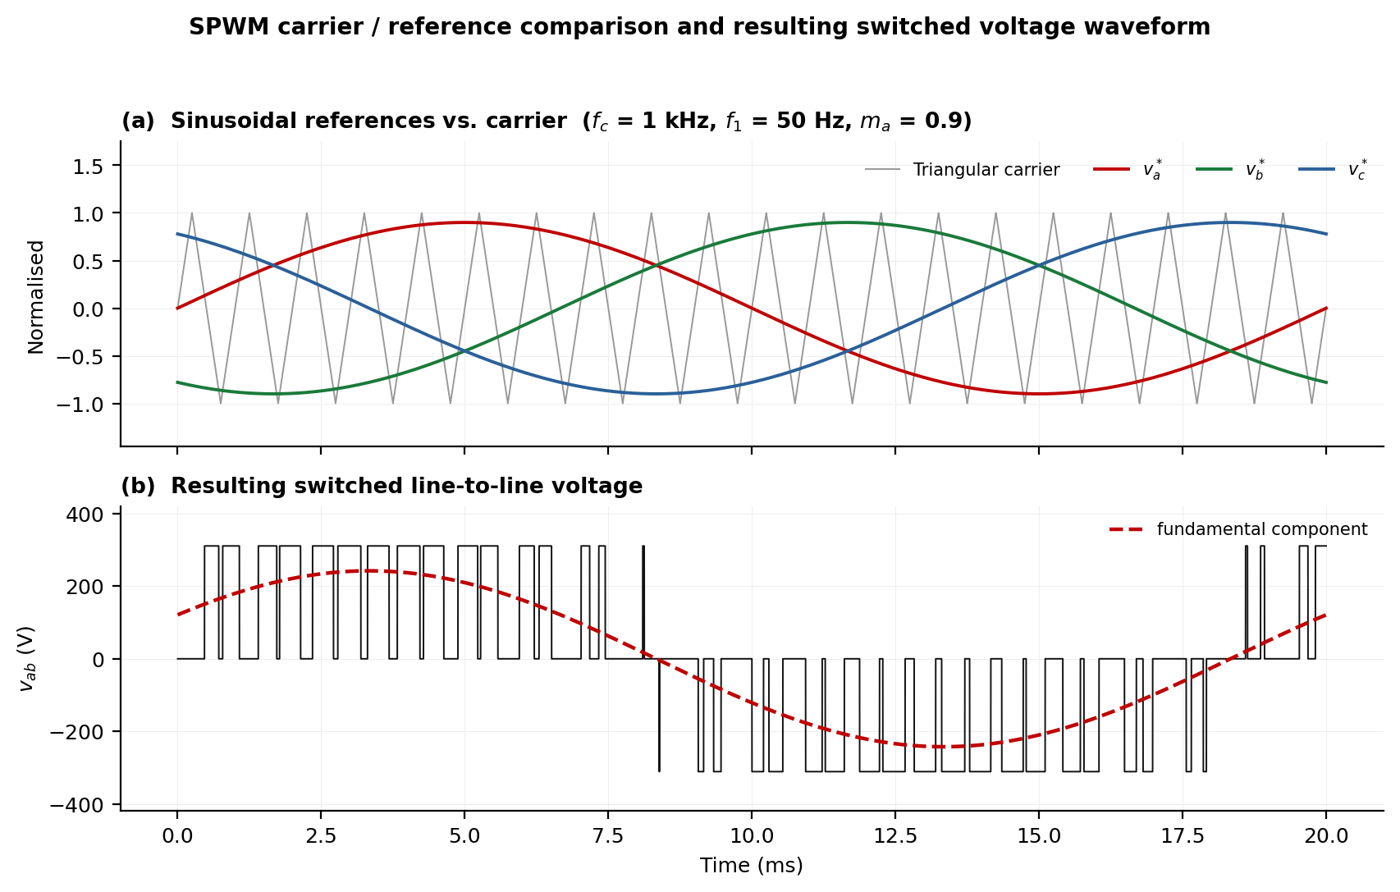
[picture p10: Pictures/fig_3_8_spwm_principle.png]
		
		\caption{SPWM carrier/reference comparison and resulting switched voltage waveform.}
		\label{fig:spwm}
	\end{figure}
	
	\subsection{Sensor Configuration}
	Two sensor types close the control and safety loops:
	\begin{itemize}
		\item \textbf{Incremental rotary encoder}, coupled directly to the keyed spindle
		shaft, provides RPM and angular position feedback to the PID speed loop
		(Section~3.6) with zero slip relative to the true spindle position.
		\item \textbf{Inductive proximity switch(es)}, used to confirm spindle
		stationary/clamped state before the pneumatic cylinder is permitted to actuate -- this
		is the physical sensor input to the supervisory interlock logic in Section~\ref{sec:plc_logic}
		\cite{ref14}.
	\end{itemize}
	
	\section{Mathematical Modeling}\label{sec:math_modeling}
	The spindle/motor system is modeled as a single lumped rotational inertia driven by motor
	torque and opposed by load torque and viscous friction \cite{ref8,ref9}:
	\begin{equation}
		J\dot{\omega} = T_m - T_L - B\omega
	\end{equation}
	where $J$ is the combined inertia of the motor rotor, pulley, and spindle shaft (extracted
	directly from SolidWorks mass properties on the assembly), $\omega$ is the angular velocity,
	$T_m$ is the motor electromagnetic torque, $T_L$ is the reflected load (cutting) torque from
	Section~\ref{sec:peak_force_torque}, and $B$ is the viscous friction coefficient.
	
	Including the motor electrical dynamics (armature/phase circuit), with $T_m = K_t I$ and
	back-EMF $e = K_e\omega$, the system is described by two coupled first-order equations:
	\begin{align}
		L\frac{dI}{dt} &= V - RI - K_e\omega \\
		J\frac{d\omega}{dt} &= K_t I - B\omega - T_L
	\end{align}
	Choosing the state vector $x = [I,\ \omega]^T$ and the input vector $u = [V,\ T_L]^T$
	(control and disturbance inputs respectively), these can be written in state-space form:
	\begin{equation}
		\dot{x} = Ax + Bu, \qquad y = Cx + Du
	\end{equation}
	with
	\begin{equation}
		A = \begin{bmatrix} -R/L & -K_e/L \\[2pt] K_t/J & -B/J \end{bmatrix}, \quad
		B = \begin{bmatrix} 1/L & 0 \\[2pt] 0 & -1/J \end{bmatrix}, \quad
		C = \begin{bmatrix} 0 & 1 \end{bmatrix}, \quad
		D = \begin{bmatrix} 0 & 0 \end{bmatrix}
	\end{equation}
	The two transfer functions of interest follow directly from
	$G(s) = C(sI - A)^{-1}B + D$:
	\begin{align}
		G_V(s) &= \frac{\Omega(s)}{V(s)}\bigg|_{T_L=0} = \frac{K_t}{(Js+B)(Ls+R) + K_t K_e} \\
		G_{T_L}(s) &= \frac{\Omega(s)}{T_L(s)}\bigg|_{V=0} = \frac{-(Ls+R)}{(Js+B)(Ls+R) + K_t K_e}
	\end{align}
	The first is the plant transfer function used for the pole-placement controller design
	(Section~\ref{sec:controller_design}); the second is the disturbance transfer function used
	in the disturbance-rejection analysis (Section~\ref{sec:system_dynamic}). Substituting the $J$ value and the servo motor's electrical parameters ($R$, $L$, $K_t$,
	$K_e$) gives the numeric models used in the simulations.

\section{Controller Design}\label{sec:controller_design}
A PID controller is placed in the speed loop, comparing the commanded RPM against the
encoder-derived feedback and generating the reference signal fed into the SPWM modulator
(Section~\ref{sec:pwm}), which in turn sets the effective duty cycle/voltage applied to the
motor \cite{ref9,ref17}:
\begin{equation}
	u(t) = K_p e(t) + K_i\int_0^t e(\tau)\,d\tau + K_d\frac{de(t)}{dt}
\end{equation}
Substituting the PID controller $C(s) = (K_d s^2 + K_p s + K_i)/s$ and the plant transfer
function $G(s)$ from Section~\ref{sec:math_modeling} into the unity-feedback characteristic
equation $1 + C(s)G(s) = 0$ gives the closed-loop cubic:
\begin{equation}
	a_2 s^3 + (a_1 + K_t K_d)\,s^2 + (a_0 + K_t K_p)\,s + K_t K_i = 0
\end{equation}
where the plant coefficients are $a_2 = JL$, $a_1 = JR + BL$, and
$a_0 = BR + K_t K_e$. The plant contributes two poles from its electrical and mechanical
dynamics; the PID integrator adds a third at the origin, giving the cubic characteristic
equation. Matching it to the desired monic polynomial $(s-p_1)(s-p_2)(s-p_3)$ -- with the
dominant pole pair placed by the damping ratio and natural frequency targets, and the third
pole placed an order of magnitude further left -- gives the gains:
\begin{align}
	K_d &= \frac{c_2 a_2 - a_1}{K_t} \\
	K_p &= \frac{c_1 a_2 - a_0}{K_t} \\
	K_i &= \frac{c_0 a_2}{K_t}
\end{align}
These gains meet the two performance requirements: (i) a fast, well-damped step response
from 0 to the commanded RPM, and (ii) rapid recovery of the setpoint RPM after the
disturbance torque $T_L$ (peak cutting torque, Section~\ref{sec:peak_force_torque}) is
applied, consistent with the disturbance-rejection test defined in
Section~\ref{sec:system_dynamic}.

\begin{figure}[htbp]
	\centering
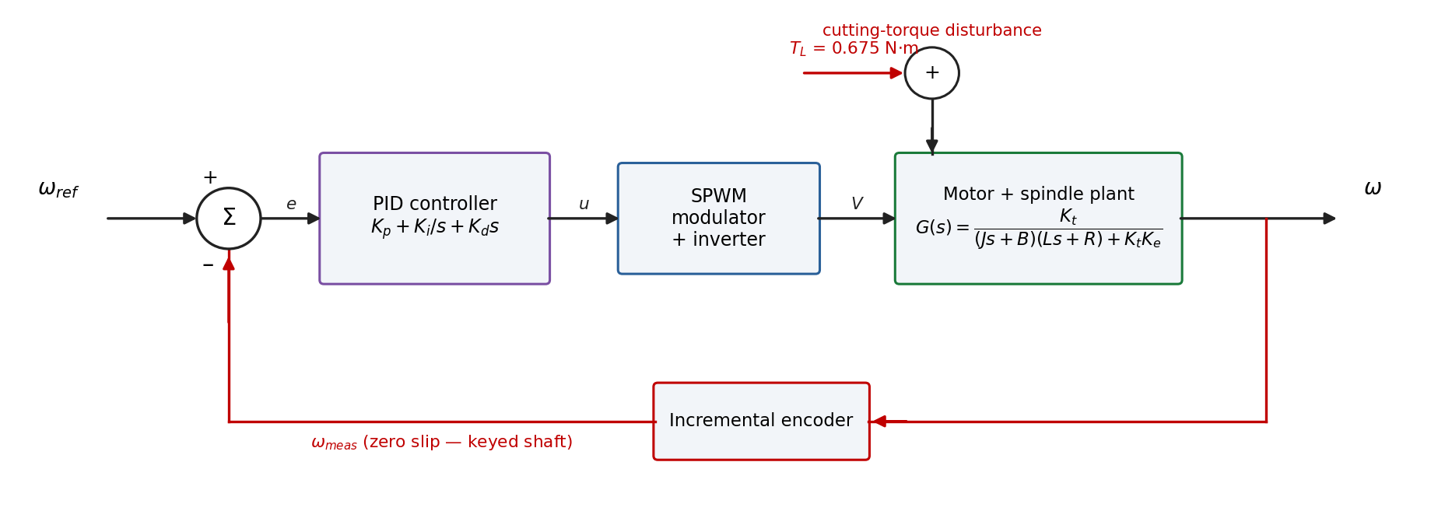
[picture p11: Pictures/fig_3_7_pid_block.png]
	
	\caption{Closed-loop PID speed control block diagram.}
	\label{fig:pid_block}
\end{figure}
	
	\section{Supervisory Logic Design}\label{sec:plc_logic}
	A supervisory interlock enforces the safety condition that the pneumatic drawbar cylinder may
	only actuate while the spindle is stationary, preventing the cylinder from firing into a
	rotating spindle \cite{ref14}:
	\begin{table}[htbp]
		\centering
		\caption{Supervisory interlock truth table for the pneumatic drawbar cylinder.}
		\label{tab:plc_truth}
		\begin{tabular}{cccl}
			\toprule
			Tool-change requested & Spindle RPM $\leq 5$ & \texttt{Cylinder\_Actuate} & Result \\
			\midrule
			0 & -- & 0 & No action \\
			1 & 0 & 1 & Cylinder fires -- tool change proceeds \\
			1 & $\neq 0$ & 0 & \textbf{Interlocked} -- deceleration commanded first \\
			\bottomrule
		\end{tabular}
	\end{table}
	\begin{equation}
		\texttt{Cylinder\_Actuate} = \text{TRUE} \iff (\texttt{Tool\_Change\_Request} = \text{TRUE})
		\land (\texttt{Spindle\_RPM} \leq 5)
	\end{equation}
	
	\begin{figure}[h]
		\centering
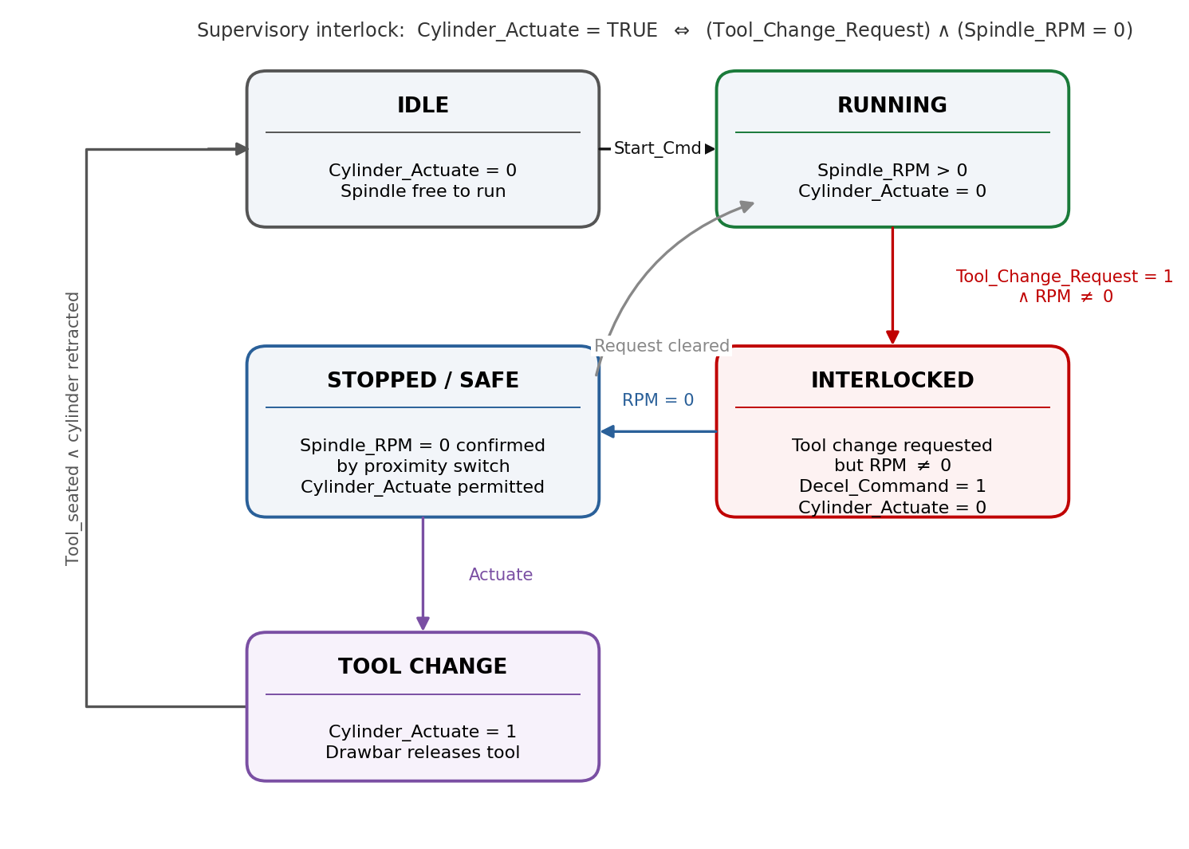
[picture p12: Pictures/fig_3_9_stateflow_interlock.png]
		
		\caption{Stateflow/PLC logic diagram for the tool-change safety interlock.}
		\label{fig:stateflow}
	\end{figure}
	
	% =====================================================
	% CHAPTER 4: SIMULATION RESULTS AND DISCUSSION
	% =====================================================
	\chapter{Simulation Results and Discussion}
	
	\section{Mechanical Analysis Results}
	The mechanical results combine the analytical hand calculations of
	Section~\ref{sec:shaft_design} with the beam finite-element study of the spindle shaft,
	cross-checked against the overhung-load bearing reactions derived in
	Section~\ref{sec:overhung_bending}. The two methods agree to within 0.1\% on the peak
	bending stress, and the beam model's computed bearing reactions reproduce the closed-form
	values exactly ($-336.4$~N at the rear bearing, $+471.4$~N at the front bearing),
	confirming both the analytical model and its numerical implementation.
	
	\begin{table}[htbp]
		\centering
		\caption{Summary of mechanical analysis results against governing design checks.}
		\label{tab:mech_results}
		\begin{tabular}{lcccc}
			\toprule
			Load Case & Component & Result & Governing Check & Verdict \\
			\midrule
			Cutting load & Shaft & $\sigma_{vm}=25.9$~MPa & FoS $\approx 28.3$ vs.\ yield & Safe, stiffness-governed \\
			Drawbar load & Housing shoulder & 30.2--41.3~MPa & FoS 12.2--16.7 & Safe \\
			Drawbar load & Puller plate & 132--181~MPa & FoS 2.5--3.5 & Safe \\
			Cutting load & Bearings & $L_{10h}\approx31{,}350$~h & vs.\ $L_{10h}\geq20{,}000$~h & Safe \\
			\bottomrule
		\end{tabular}
	\end{table}
	
	\section{Power \& Electrical Simulation Results}
	A Simulink model of the power-electronics drive stage (single-phase rectifier -- DC link --
	IGBT inverter, SPWM-switched, per the architecture in Sections~\ref{sec:vfd_arch} and~\ref{sec:pwm}) was built and
	simulated. The rectifier produces a DC-link voltage of approximately 310--317~V from the
	230~V single-phase AC supply, and the inverter generates the commanded three-phase output.
	The SPWM carrier/reference intersection drives the switched voltage waveform shown in
	Figure~\ref{fig:spwm_result}, and the resulting phase current is near-sinusoidal at the
	commanded electrical frequency, as expected once the motor winding inductance filters the
	switching ripple.
	
	\begin{figure}[h]
		\centering
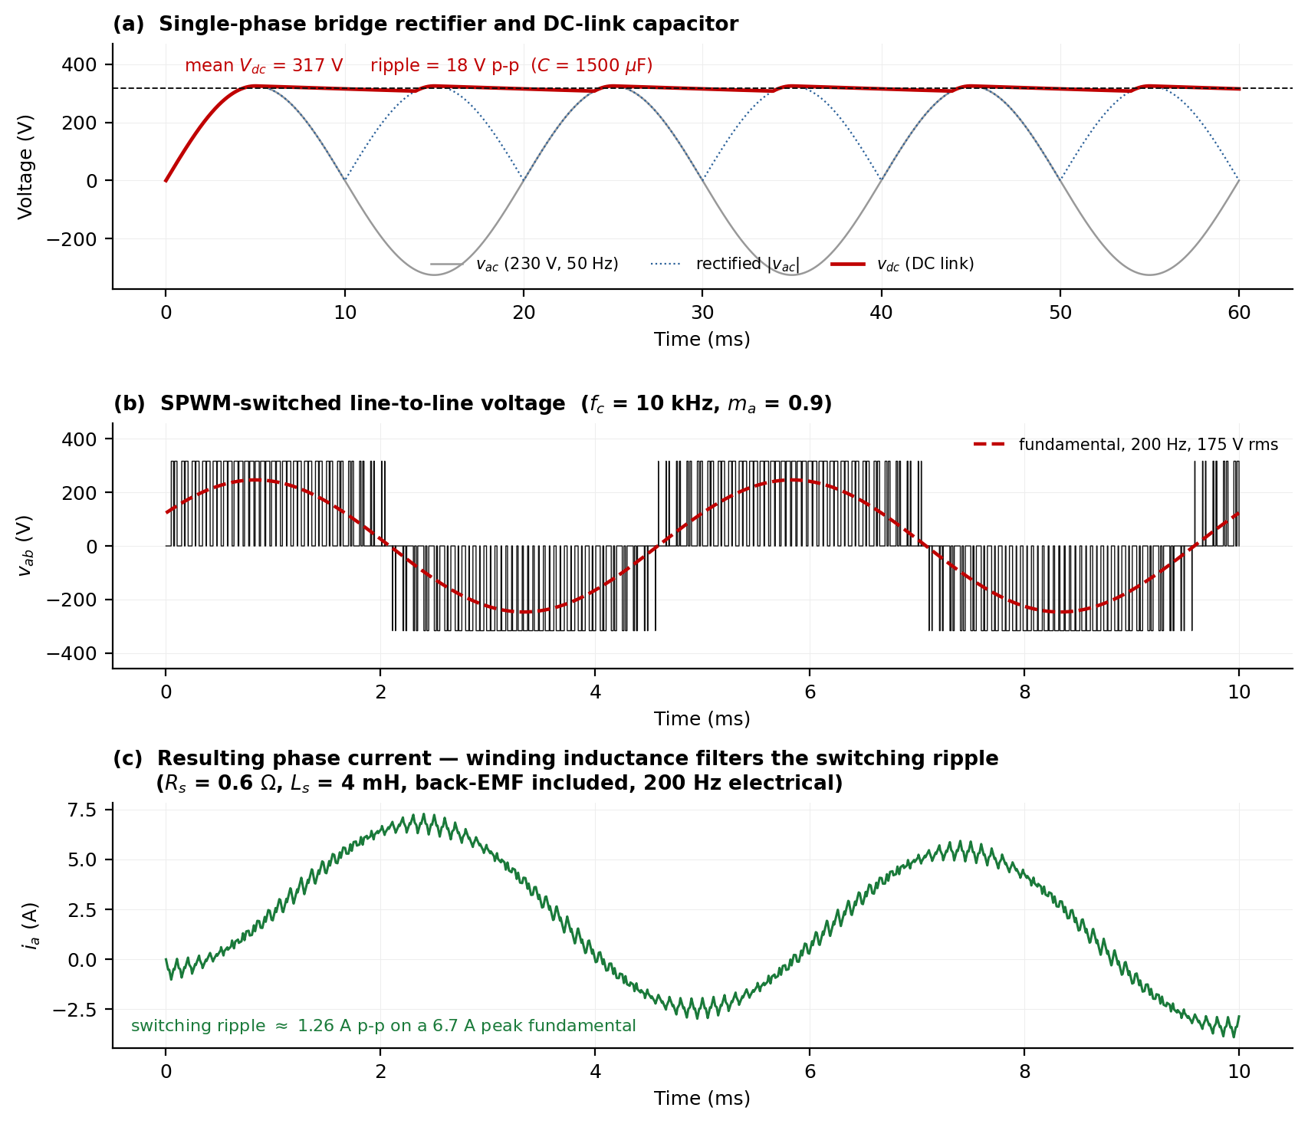
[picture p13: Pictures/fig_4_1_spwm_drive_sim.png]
		
		\caption{Simulated SPWM carrier/reference intersection and resulting switched voltage waveform.}
		\label{fig:spwm_result}
	\end{figure}
	
\section{System Dynamic \& PID Results}\label{sec:system_dynamic}
The PID controller designed in Section~\ref{sec:controller_design} is implemented in MATLAB
using the Control System Toolbox, and evaluated against the two closed-loop requirements:
fast tracking of a commanded speed change, and rapid recovery from the peak cutting-torque
disturbance of Section~\ref{sec:peak_force_torque}. The root locus, Bode plot, closed-loop
step response, and disturbance response below are all evaluated at the design operating
point, with the gains obtained directly from the pole-placement solution.

\begin{figure}[H]
	\centering
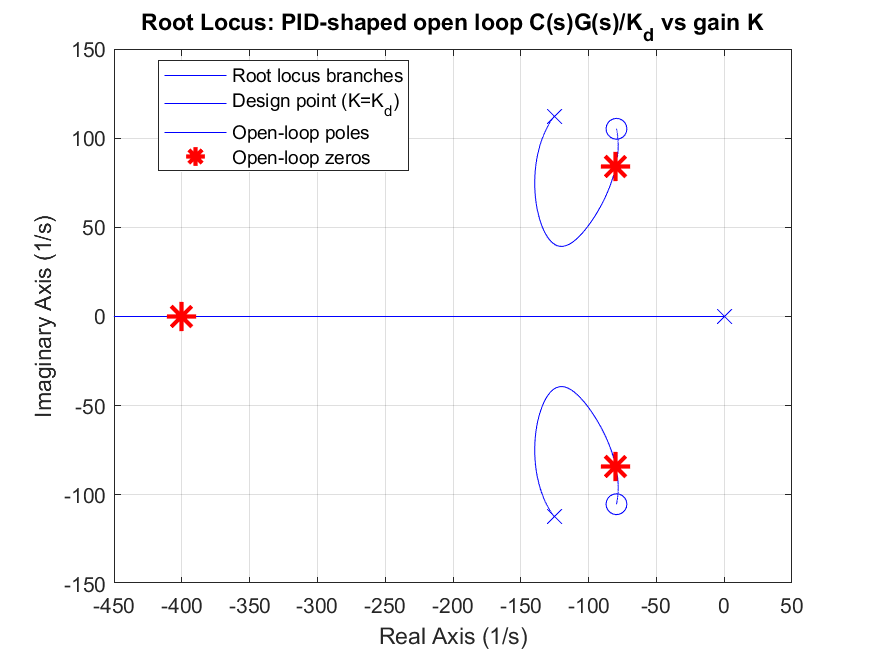
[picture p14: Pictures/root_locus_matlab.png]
	
	\caption{Root locus of the PID-shaped open loop, gain $K$ swept from 0 to 10; the design
		point ($K=K_d$) is marked with a red star at the target dominant poles.}
	\label{fig:root_locus_result}
\end{figure}

\begin{figure}[H]
	\centering
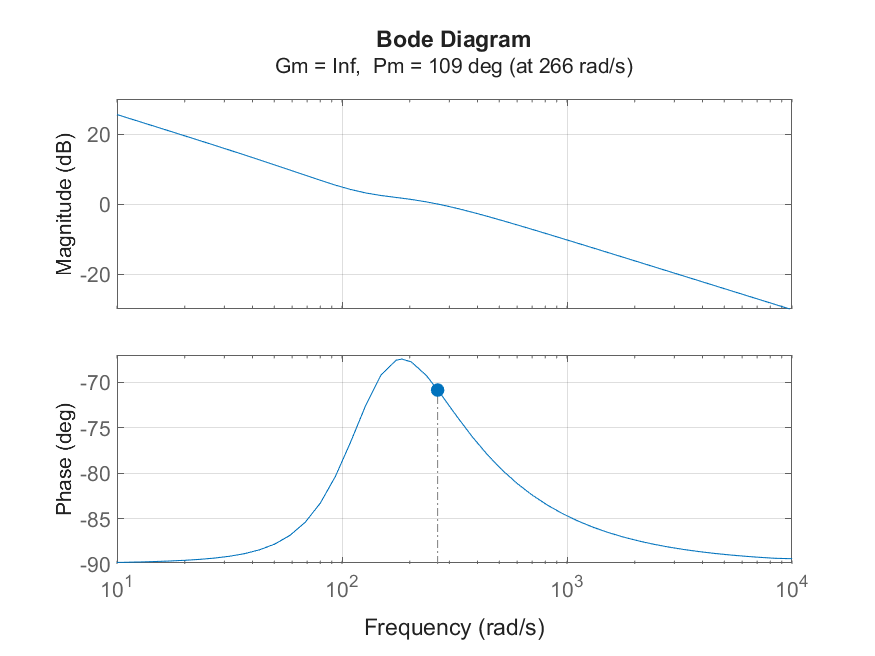
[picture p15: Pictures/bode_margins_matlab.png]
	
	\caption{Open-loop Bode plot with stability margins: infinite gain margin,
		$109^\circ$ phase margin at 266~rad/s.}
	\label{fig:bode_result}
\end{figure}

\begin{figure}[H]
	\centering
	
	\caption{Closed-loop step response to a commanded speed change.}
	\label{fig:step_result}
\end{figure}

\begin{figure}[H]
	\centering
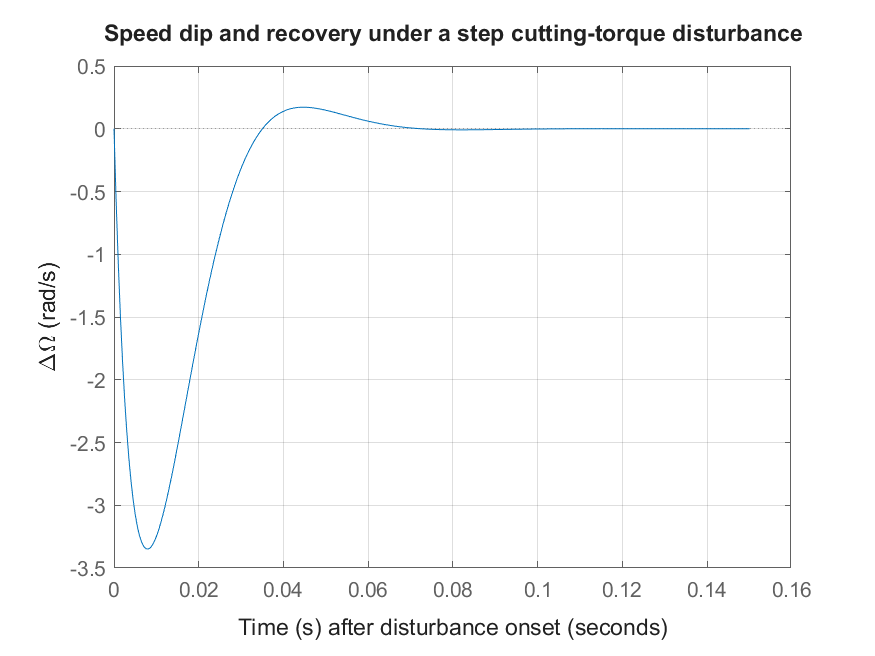
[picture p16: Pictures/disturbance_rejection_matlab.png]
	
	\caption{Speed dip and recovery under a step cutting-torque disturbance (peak cutting
		torque, Section~\ref{sec:peak_force_torque}) applied at $t=0$ on this axis.}
	\label{fig:disturbance_result}
\end{figure}

\begin{table}[H]
	\centering
	\caption{Closed-loop PID speed-control performance metrics.}
	\label{tab:pid_metrics}
	\begin{tabular}{lc}
		\toprule
		Metric & Result \\
		\midrule
		Rise time & 16.0~ms \\
		Settling time (2\%) & 26.1~ms \\
		Overshoot & 1.08\% \\
		Peak value & 1.0108 \\
		Gain margin & Infinite \\
		Phase margin & $109.2^\circ$ at 266~rad/s \\
		Peak disturbance speed dip & $-3.35$~rad/s \\
		Disturbance recovery & essentially complete by $\sim$70--80~ms \\
		\bottomrule
	\end{tabular}
\end{table}

The achieved response exceeds the design target of Section~\ref{sec:controller_design}: the
16~ms rise time and 26~ms settling time are both substantially faster than the 50~ms target,
and the 1.08\% overshoot sits well inside the 5\% allowance. The closed-loop response is
faster and better damped than the pure second-order approximation predicts because the PID
zeros, located at $-79.45 \pm 105.26j$~rad/s, sit close to the dominant closed-loop pole
pair and partially cancel its contribution to the step response. The third pole at
$-400$~rad/s contributes only during the first $\sim$12~ms and decays quickly, leaving a
residual response that settles faster than the pure second-order prediction and with only
1.08\% overshoot.

The disturbance-rejection result confirms that the integral action performs as intended. The
peak cutting torque produces a speed dip of $-3.35$~rad/s -- roughly 0.64\% of the commanded
5000~RPM -- and the loop recovers to essentially zero steady-state error within roughly
70--80~ms. The small overshoot past zero before settling is consistent with the
$\zeta \approx 0.60$ complex zero pair identified in the PID's lead component. The
disturbance path is shaped by the sensitivity function $S(s) = 1/(1 + C(s)G_V(s))$, which
attenuates the disturbance transfer function $G_{T_L}(s)$ derived in
Section~\ref{sec:math_modeling} across the control bandwidth.
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

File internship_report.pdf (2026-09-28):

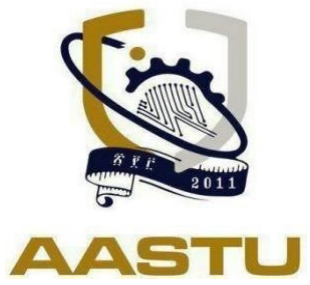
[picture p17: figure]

I

ADDIS ABABA SCIENCE AND TECHNOLOGY UNIVERSITY COLLEGE OF ENGINEERING
Department of Electro-Mechanical Engineering Addis Machine and Spare Parts Manufacturing Industry

Internship Report

Students Name | ID. No
1. Zahir Ahmed | ETS1501/15
2. Robera Kumsa | ETS1162/15
3. Samuel Tesfaye | ETS1213/15
4. Biniam Getahun | ETS0350/14

Academic Supervisor – Nebiyat Yazachew Company Supervisor – Habtamu Abebe

September 2026 G.C
Addis Ababa, Ethiopia

III

Acknowledgment

First and foremost, we would like to thank almighty God for giving us the power, persistence, and wisdom throughout our internship. His guidance has been very fundamental to our successful completion of this training program.

We would also like to extend our appreciations to the Department of Electro-Mechanical Engineering at Addis Ababa Science and Technology University for organizing this valuable internship and availing us this opportunity through the linkage between the university and industry. This training has given us hands-on experience that supplements the theoretical knowledge we have obtained during our course work.

Special thanks go to our company supervisor, Habtamu Abebe, for his continuous support, guidance, and encouragement throughout the time we spent facing many challenges in the Addis Machine and Spare Parts Manufacturing Industry. We would also like to extend our thanks to all the staff at the company who assisted us, cooperated with us, and made us feel welcome during this interesting and educative internship.

Finally, we would like to extend our heartfelt gratitude to our academic advisor, Mr. Nebyat Yazachew, for instructive supervision, stimulating advice, and the willingness to guide us through every step of the project. He made a big difference in our learning and the entire experience of the internship. It would have been far from easy to face some of the difficulties that we had both in the workplace environment and in developing our project without his encouragement and guidance.

We are indeed grateful to one and all for the combined efforts of all about the success of our internship and growth of ourselves as professionals in the field of electro-mechanical engineering.

IV

Catalog

Acknowledgment | II
List of figures | III
List of Abbreviations | VII
1.3. Main Customers or End Users of Addis Machine and Spare Parts Manufacturing Industry

V

VII

# List of figures

Figure 2. 2 Circuit Diagram of Forward and Reverse Motor Starting Method with Interlock

# Chapter 1

### 1. Brief History of Addis Machine and Spare Parts Manufacturing Industry

(AMSMI)

1.1.Background of the company

The Addis Machine and Spare Parts Manufacturing Industry (AMSMI), previously known as Hibret Manufacturing and Machine Building Industry, has a rich history tied to Ethiopia’s industrial and defense development. Founded in 1945 E.C. under Emperor Haile Selassie, it was established as part of a strategic effort to modernize Ethiopia’s industrial capabilities.

The factory was created to support Ethiopia’s vision of achieving military self-reliance and reducing dependency on foreign imports. Amid a shifting geopolitical environment, the need for a robust defense sector and industrial foundation became evident. Emperor Haile Selassie prioritized the development of domestic manufacturing to strengthen national sovereignty and sustain growth. AMSMI’s initial focus was on producing small-scale military logistics, such as ammunition, medals, badges, and spare parts for military and industrial equipment, which were vital for bolstering Ethiopia’s defense capabilities and national security.

### 1.1.1. International Collaboration

The factory was established through a partnership between the Ethiopian government and Czechoslovakia, capitalizing on the latter’s expertise in industrial and defense manufacturing. A Czech national was appointed as the first manager, providing essential technical and managerial expertise for the factory’s initial operations. This collaboration reflected Ethiopia’s commitment to international partnerships to bolster its industrial sector, enabling critical technology and knowledge transfers that were foundational to the country’s early manufacturing industry.

Initially, the factory focused on supplying Ethiopia’s military with essential logistics, such as ammunition. Over time, as its potential became evident, the government expanded its role to support broader national industrialization goals.

### 1.1.2. Expansion and Diversification

As Ethiopia’s industrial and military demands grew, AMSMI adapted accordingly. In the decades after its founding, the factory significantly expanded its manufacturing capabilities and economic role. By the 1970s and 1980s, it began producing civilian industrial machinery and spare parts alongside its military products, enabling AMSMI to contribute to both defense and civilian development.

In the early 2000s, Ethiopia pursued accelerated industrialization as part of its economic growth strategy, prompting reforms to modernize infrastructure and manufacturing. In 2002 E.C., the factory was renamed Addis Machine and Spare Parts Manufacturing Industry (AMSMI), reflecting its expanded mission to produce not only military equipment but also machinery and spare parts
to support Ethiopia’s burgeoning industrial sector.

### 1.1.3. Integration into METEC

To support Ethiopia’s push for industrial development, AMSMI was incorporated into the Metals and Engineering Corporation (METEC) in 2002 E.C., a state-owned entity tasked with driving the nation’s industrial transformation. METEC was formed as a major conglomerate to oversee Ethiopia’s engineering and manufacturing sectors, aiming to advance industrialization by utilizing local resources, technology, and expertise to produce infrastructure, machinery, and equipment for both civilian and defense purposes.

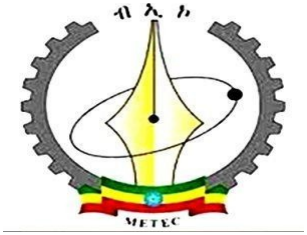
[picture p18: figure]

Figure 1. 1 Logo of METEC

### 1.1.4. Challenges Faced Under METEC

Under METEC, AMSMI saw growth but faced significant challenges. By the late 2010s, METEC and its subsidiaries, including AMSMI, were criticized for mismanagement, corruption, and inefficiencies. METEC’s role in major projects like the Grand Ethiopian Renaissance Dam (GERD) and sugar factories was marred by delays and financial irregularities, drawing public scrutiny.

In 2020, the Ethiopian government intervened, dissolving METEC as part of a broader reform to enhance transparency and accountability in public enterprises. This marked the end of METEC’s tenure but provided AMSMI an opportunity to restructure and redefine its identity.

### 1.1.5. Rebranding as Part of Ethio Engineering Group

After METEC’s dissolution in 2020, AMSMI was restructured and integrated into the newly established Ethio Engineering Group (EEG) to enhance efficiency and transparency in Ethiopia’s industrial sector. Under EEG, AMSMI refocused on manufacturing industrial machinery and spare parts for civilian and military use, emphasizing innovation, quality, and market expansion. By producing high-quality goods, AMSMI supports Ethiopia’s industrialization goals, reduces reliance on imports, and strengthens local manufacturing, solidifying its role as a key player in the nation’s economic and industrial growth.

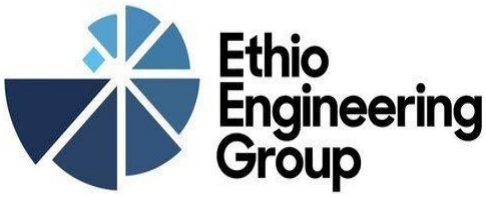
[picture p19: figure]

Figure 1. 2: Ethio-Engineering Group logo

1.2.Main Products and Services:

AMSMI's Evolution as a Leading Producer of Industrial Machinery and Spare Parts

Addis Machine and Spare Parts Manufacturing Industry (AMSMI) has become a cornerstone of Ethiopia’s industrial supply chain, emerging as a leading producer of industrial machinery and spare parts. Through innovation, expansion, and a commitment to quality, AMSMI supports diverse sectors, including manufacturing, agriculture, transport, and defense, contributing to Ethiopia’s economic growth and industrial self-reliance. Its expertise in producing machinery and spare parts enhances operational efficiency across industries in Ethiopia and East Africa. Below are some of the primary products and services offered by AMSMI:

### 1.2.1. Industrial Machinery Production:

AMSMI manufactures a range of industrial machinery critical for sectors like manufacturing, construction, and agriculture. Its lathe machines enable precise cutting and shaping of metal for vehicle components, machinery, and infrastructure projects. Milling machines offer high precision for shaping materials used in machinery, construction, and agricultural equipment. Shearing machines provide efficient metal sheet cutting for metal fabrication and construction. Radial drill machines support heavy-duty drilling for large workpieces in engineering and manufacturing. Rolling machines shape metal plates for applications in automotive and construction industries.

### 1.2.2. Spare Parts Production:

AMSMI is a key producer of high-quality spare parts essential for machinery maintenance across various sectors, minimizing downtime and boosting productivity. Its gears, including spur, helical, and sprocket types, facilitate power transmission in agriculture, manufacturing, and automotive applications. Shafts deliver rotational force for vehicles and industrial machines. Molds and dies enable precise material shaping in plastics and metalworking industries. Brake pads ensure safe operation in vehicles and machinery, enhancing reliability and efficiency.

### 1.2.3. Fabrication Services:

AMSMI provides advanced fabrication services to meet diverse client needs, producing customized parts and structures for industries. Its steel structure fabrication supports Ethiopia’s infrastructure development, creating durable components for buildings, bridges, and industrial facilities. Body structure fabrication delivers tailored solutions for industrial machinery and vehicles, ensuring efficient and safe operation. AMSMI also produces high-quality bolts and nuts, essential for assembling machinery, vehicles, and infrastructure projects, ensuring secure construction and maintenance.

### 1.2.4. Brake Pads and Related Products

As a leader in brake-related products, AMSMI ensures safety and efficiency in vehicles and industrial machinery. Its durable brake pads serve commercial vehicles, agricultural machinery, and industrial equipment, offering reliable stopping power in demanding environments. AMSMI also produces brake lines and brake shoes, designed for heavy-duty use to maintain robust and safe braking systems.

### 1.2.5. Consultancy and Maintenance Services:

AMSMI provides consultancy and maintenance services to enhance machinery and production efficiency. Consultancy offers expert guidance to optimize performance. Maintenance services keep equipment in top condition, minimizing downtime and costs. Material testing ensures products meet high-quality standards. Heat treatment improves metal component strength and durability. Machine erection services handle proper installation and commissioning. Training programs equip technicians and engineers with skills to operate and maintain machinery effectively, reducing operational risks.

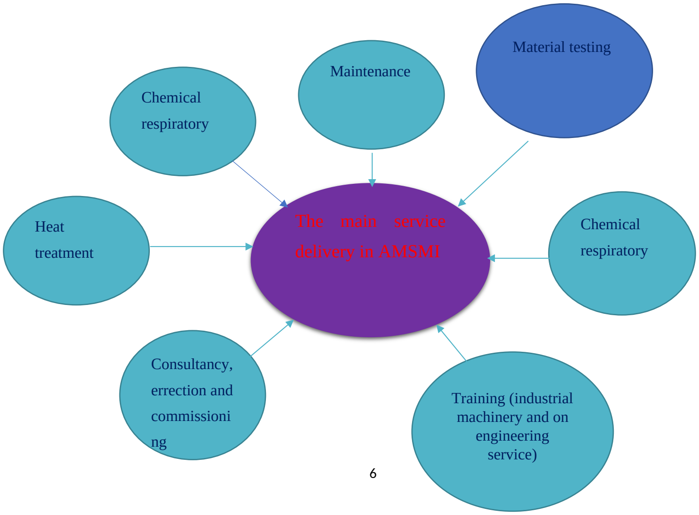
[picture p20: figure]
Material testing; Maintenance; Heat treatment; Consultancy, errection and commissioni ng; Chemical respiratory; Training (industrial machinery and on engineering service); The main service delivery in AMSMI

Figure 1. 3 : Visual Summary of Major Services of AMSMI

Industrial Machinery: AMSMI produces a wide range of industrial machinery to support Ethiopia’s expanding industrial sector, including lathe machines for shaping metal, wood, and other materials; milling machines for precise cutting and shaping; shearing machines for cutting sheet metal; radial drill machines for heavy-duty drilling; and rolling machines for bending and forming metal plates and sheets.

Spare Parts: AMSMI specializes in manufacturing essential spare parts, such as gears (including worm, spur, helical, and sprocket types), shafts critical for machinery operation, molds, dies, and punches for industrial manufacturing, and brake pads vital for vehicles and industrial equipment.

Fabrication Services: AMSMI offers high-quality fabrication services, including steel structure fabrication for construction and industrial projects, body structure fabrication for industrial equipment, and production of bolts and nuts essential for machinery assembly.

Brake Pads: AMSMI is a leading manufacturer of brake pads, brake lines, and brake shoes for vehicles and industrial machinery, ensuring safety and efficiency in transportation and equipment operations.

Additional Services: AMSMI provides supplementary services, including consultancy for machinery setup and optimization, maintenance services for industrial equipment, material testing to ensure part quality and durability, heat treatment to enhance metal part strength, machine erection for installation and commissioning, and training programs to improve technicians’ and engineers’ skills in machinery operation and maintenance.

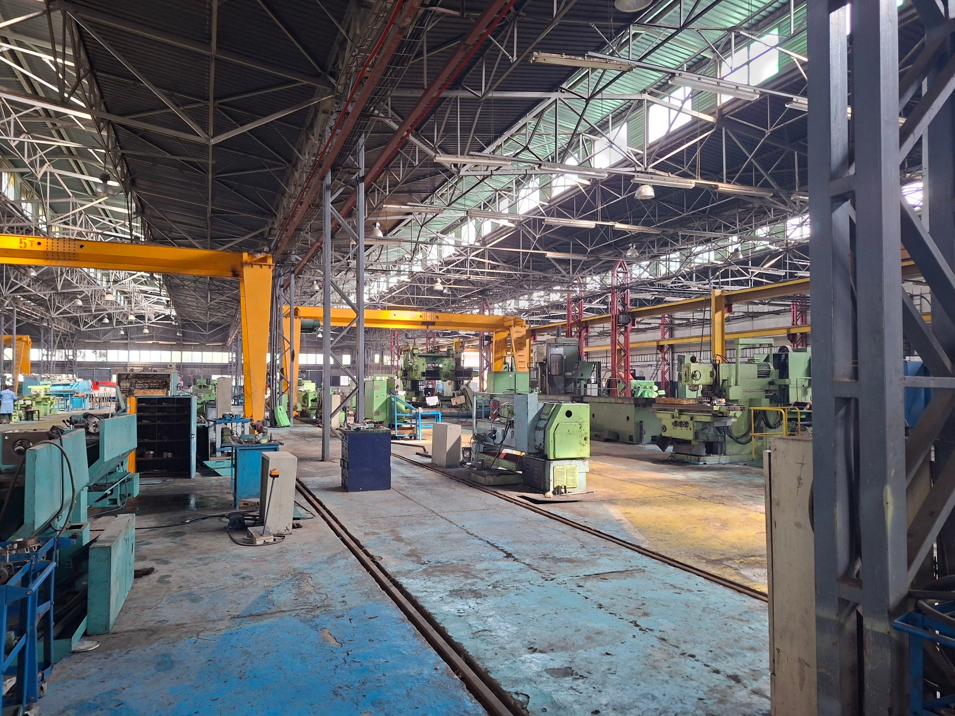
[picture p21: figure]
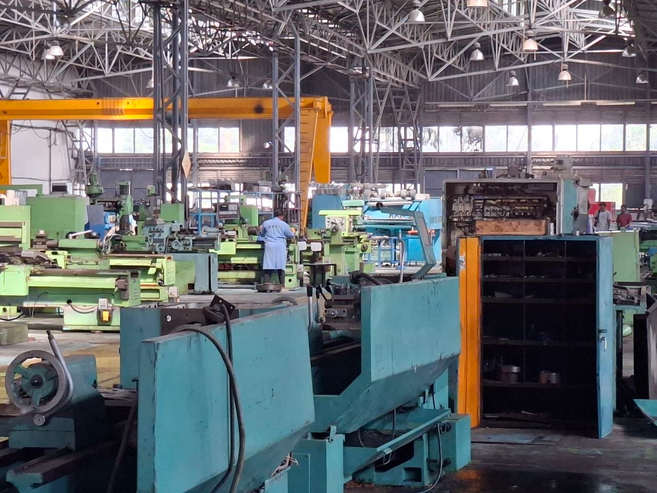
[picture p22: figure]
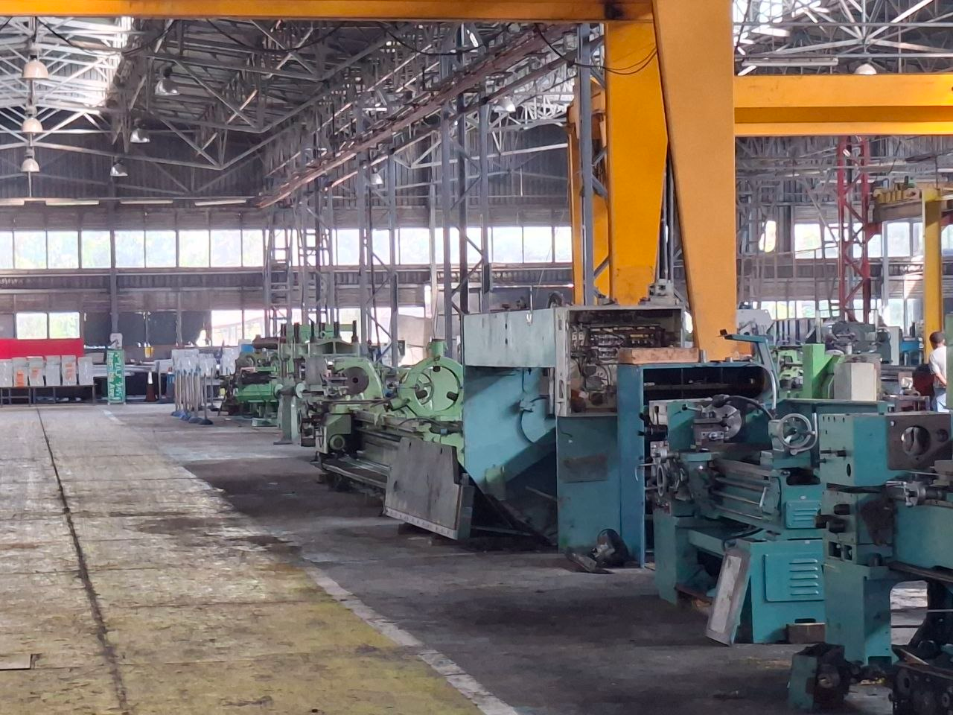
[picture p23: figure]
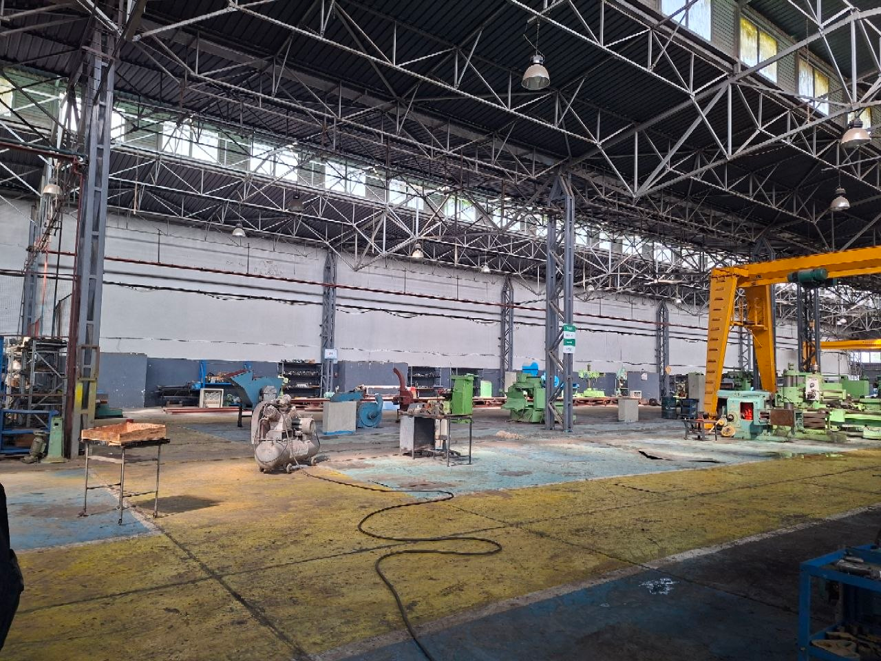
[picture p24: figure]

Figure 1. 4: Machinery Used to Perform the Above Listed Tasks

By offering such a wide range of products and services, AMSMI positions itself as a one-stop shop for the industrial and manufacturing needs of various sectors across Ethiopia.

1.3.Main Customers or End Users of Addis Machine and Spare Parts Manufacturing Industry (AMSMI)

AMSMI serves a broad and diverse customer base across multiple sectors, positioning itself as a critical partner for industries that depend on high-quality machinery and spare parts for their operations. Its products and services are essential to both the public and private sectors, contributing to the growth and sustainability of industries in infrastructure development, manufacturing, agriculture, and beyond. Below is a more detailed explanation of AMSMI's key customer segments and the roles they play in Ethiopia's industrial ecosystem:

### 1.3.1. Government Entities

AMSMI is a cornerstone of Ethiopia’s public sector, supplying critical machinery and spare parts for government-led infrastructure, defense, and transportation projects. Its products, including lathe, milling, and drilling machines, as well as gears and brake pads, support major initiatives like road networks, dams, and railways, while also maintaining government transportation fleets, ensuring efficient public services.

In defense, AMSMI upholds its legacy by providing military logistics, such as spare parts for vehicles and machinery, bolstering national security. It also supports water management, energy, and agricultural projects, driving Ethiopia’s modernization and infrastructure growth with essential equipment and components, cementing its role in the nation’s industrial and economic progress.

### 1.3.2. Manufacturing Companies

AMSMI is a vital supplier to Ethiopia’s growing manufacturing industry, providing high-quality spare parts, brake pads, and machinery to ensure consistent production and prevent costly downtime. Its reliable components and equipment enhance operational efficiency for manufacturers.

AMSMI delivers essential spare parts, including gears, shafts, bearings, and molds, to keep machinery operational, reducing financial losses from breakdowns. Its machinery, such as lathe machines, milling machines, and drill presses, supports precision manufacturing to meet domestic and export demands. AMSMI’s brake pads, used in vehicles and industrial machinery, ensure safety and reliability. Additionally, its maintenance and consultancy services, including check-ups, repairs, and adjustments, prevent equipment failures, extend machinery lifespan, and maintain uninterrupted production schedules.

### 1.3.3. Agriculture and Agro-Processing

Ethiopia’s agriculture sector, a vital component of the nation’s economy, relies heavily on AMSMI for specialized machinery, equipment, and spare parts to boost productivity and efficiency in farming and agro-processing. AMSMI’s contributions support modernization efforts, addressing the growing demand for food domestically and internationally.

AMSMI supplies durable farm machinery for plowing, harvesting, and irrigation, reducing labor and increasing yields for farmers. It provides essential spare parts, such as gears, hydraulic components, and engine parts, to maintain agricultural equipment under harsh conditions, minimizing downtime during critical seasons. For agro-processing, AMSMI delivers machinery and parts for processing, packaging, and storing agricultural products, supporting efficient production for domestic and export markets. Additionally, AMSMI offers cost-effective equipment for smallholder farmers, enhancing their livelihoods and aligning with Ethiopia’s agricultural development goals.

### 1.3.4. International Markets

AMSMI is expanding its presence beyond Ethiopia, aiming to become a leading supplier of industrial machinery, spare parts, and brake pads in East Africa and beyond, supporting regional industrialization.

The company exports machinery and spare parts to countries like Kenya, Sudan, Djibouti, and South Sudan, aiding their manufacturing and infrastructure development while fostering regional economic growth. AMSMI’s products support East Africa’s infrastructure projects in construction, agriculture, and defense, establishing it as a key partner in the region’s industrialization. Additionally, AMSMI is exploring new markets in North Africa, the Middle East, and Sub-Saharan Africa, leveraging its manufacturing expertise to meet diverse industrial needs and expand its global footprint.

1.4.Overall Organization and Workflow

AMSMI’s organizational structure ensures efficient production and service delivery through specialized departments. The production department manufactures machinery, spare parts, and fabrication products, adhering to strict quality and delivery standards. The R&D department drives innovation, designing new products and enhancing existing ones to maintain market competitiveness. Marketing and sales manage customer relations, promote products, and explore new business opportunities. The finance department oversees budgeting, cost management, and financial stability, while HR handles recruitment, training, and employee development. The maintenance department minimizes downtime by keeping machinery operational. AMSMI’s workflow follows a streamlined process: R&D designs products, production manufactures them
to high standards, rigorous testing ensures quality, and products are delivered to clients, with ongoing improvements to machinery and skills to sustain a competitive edge.

# Chapter2

### 2. Overall internship experience

The internship at the machine building, machine body, and bolt and nut manufacturing factory provided us with an enlightening experience. We gained extensive insight into the operations of both bolt and nut production and machine body manufacturing. Despite lasting only three months, the internship offered us valuable hands-on experience. We were involved in nearly every aspect of the manufacturing process, which deepened our understanding of mechanical and electrical components. This exposure allowed us to appreciate the intricacies of production and the importance of precision in manufacturing. Additionally, we had learned about the various stages of production, from raw material selection to quality control measures. Observing the workflow and collaboration among different teams highlighted the significance of teamwork in achieving operational success. generally, this experience significantly enhanced our knowledge of the industry and the professional principles that guide a successful organization. The skills and insights we acquired will be invaluable as we move forward in our careers.

2.1.Sections of the Company we Worked In
Throughout our internship at Ethio Engineering Group, we had the opportunity to work in multiple sections of the company mostly in conventional and machine building factory’s ranging from bolt and nut production to CNC machine maintenance and operation, gear and shaft production on the conventional store. We had been working in some the sections of the factory. The industrial unit had the following shops namely; bolt and nut manufacturing, machine body and structure building, machine building factory.

This exposure gave us a well-rounded experience in both the manufacturing and maintenance aspects of mechanical components. These hands-on experiences helped bridge the gap between our theoretical knowledge and practical application, significantly enhancing our skills.

### 2.1.1. Bolt and Nut Production section

In the bolt and nut production section, we was directly involved in the manufacturing process of these essential fasteners, which are crucial in vehicle and machinery assembly. My responsibilities included:

- Operating forging, threading, and cutting machines used to form bolts and nuts from raw materials.
- Ensuring quality control by regularly measuring and inspecting the produced components to meet precise specifications.
- Assisting with the maintenance of production machinery, ensuring they remained operational and efficient.

This experience helped us understand the critical role that precision manufacturing and quality assurance play in the mechanical components industry.

### 2.1.2. Gear and Shaft Production

In the gear and shaft production section, I worked on the manufacturing of gears and shafts—key components used in vehicles, machinery, and various industrial applications. This section allowed me to develop skills in:

- Gear Cutting and Shaping: I learned how to operate specialized machines such as gear hobbing machines, which cut teeth into the gears. This process requires high precision to ensure that the gears mesh properly with other mechanical parts.
- Shaft Manufacturing: I worked on lathes and grinding machines to shape and finish shafts, ensuring they met the required tolerances for smooth operation within gearboxes and other mechanical systems.
- Heat Treatment Processes: I gained knowledge about heat treatment, a crucial step in strengthening gears and shafts to enhance their durability and performance. This involved hardening the surface of components to resist wear and tear.

By working in this section, I gained a deep understanding of the critical role of gears and shafts in transmitting mechanical power. This experience also emphasized the importance of dimensional accuracy and surface finishes to ensure the longevity and performance of these components.

### 2.1.3. CNC Machine Maintenance

In the CNC machine maintenance section, I assisted with the repair and maintenance of advanced CNC machines used in cutting and shaping metal parts. My responsibilities included:

- Performing routine maintenance such as lubrication and calibration to keep the machines running smoothly.
- Diagnosing and fixing mechanical and electrical issues, including tool misalignment, motor faults, and wiring problems.
- Assisting in programming CNC machines to meet specific production requirements, improving my understanding of machine operation and automation.

This section honed my skills in troubleshooting and maintaining complex automated systems, giving me a strong foundation in both the mechanical and electrical aspects of CNC machines.
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

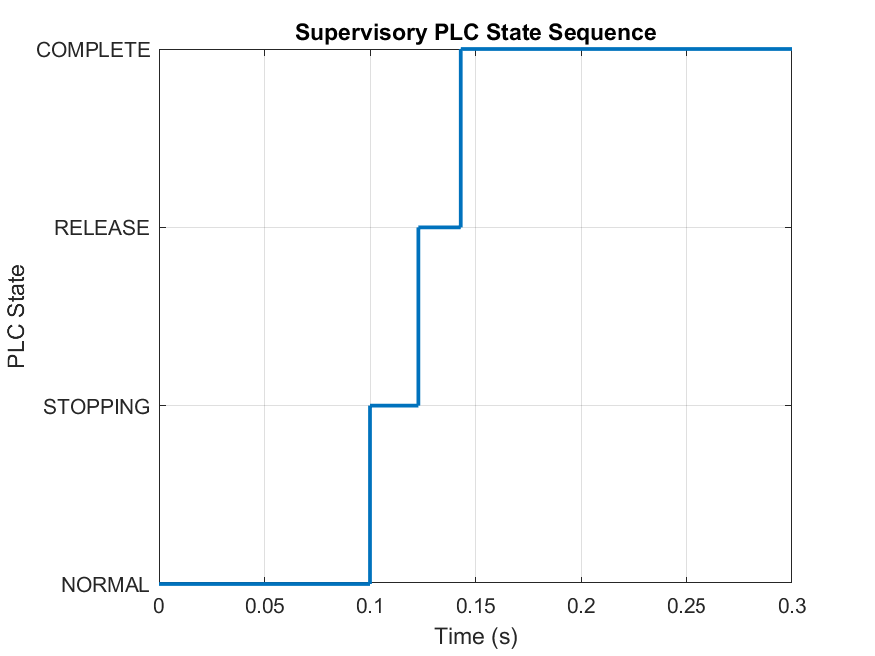
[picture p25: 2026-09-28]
Pictures/plc_state_sequence.png

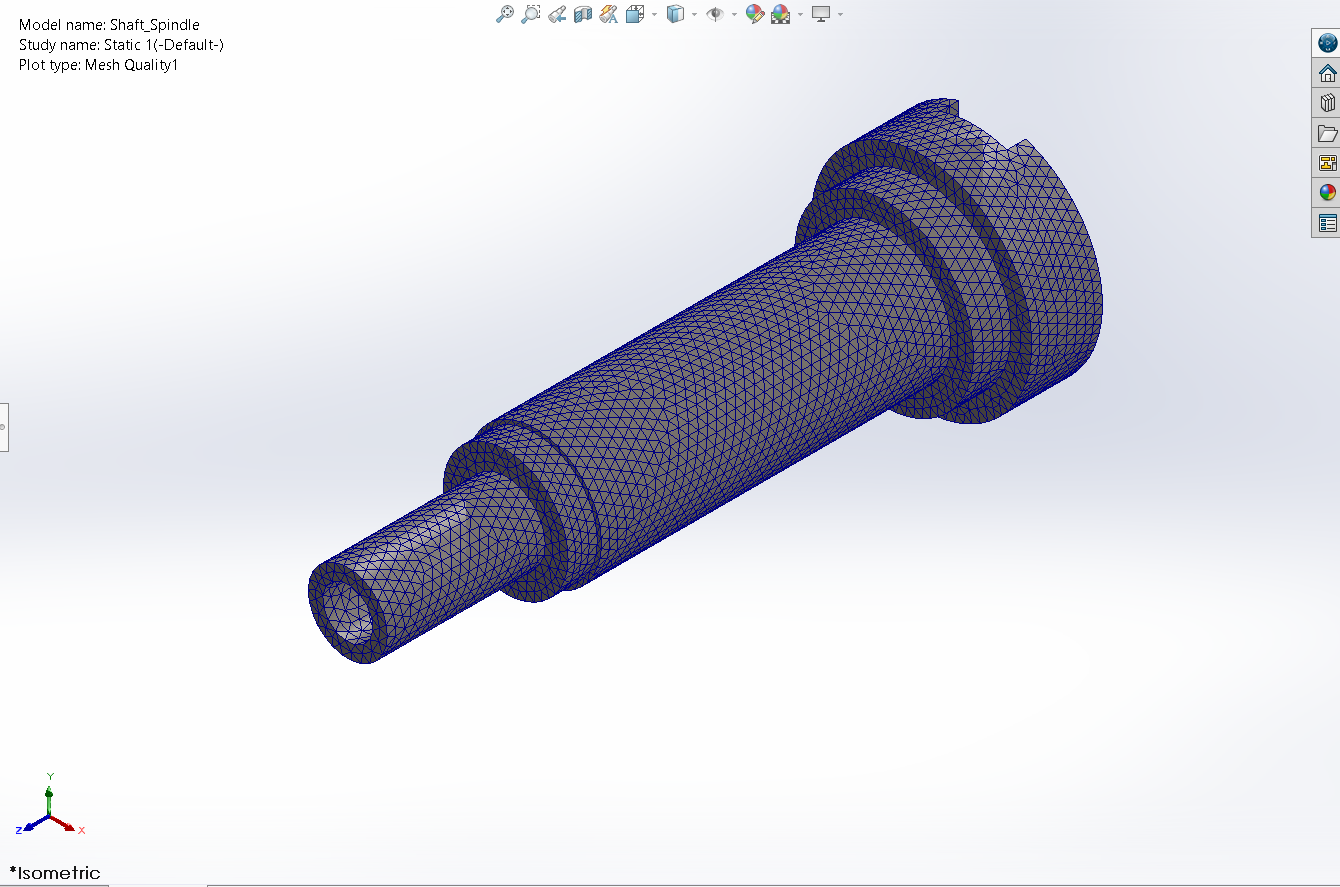
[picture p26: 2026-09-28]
Pictures/Mesh-1.png

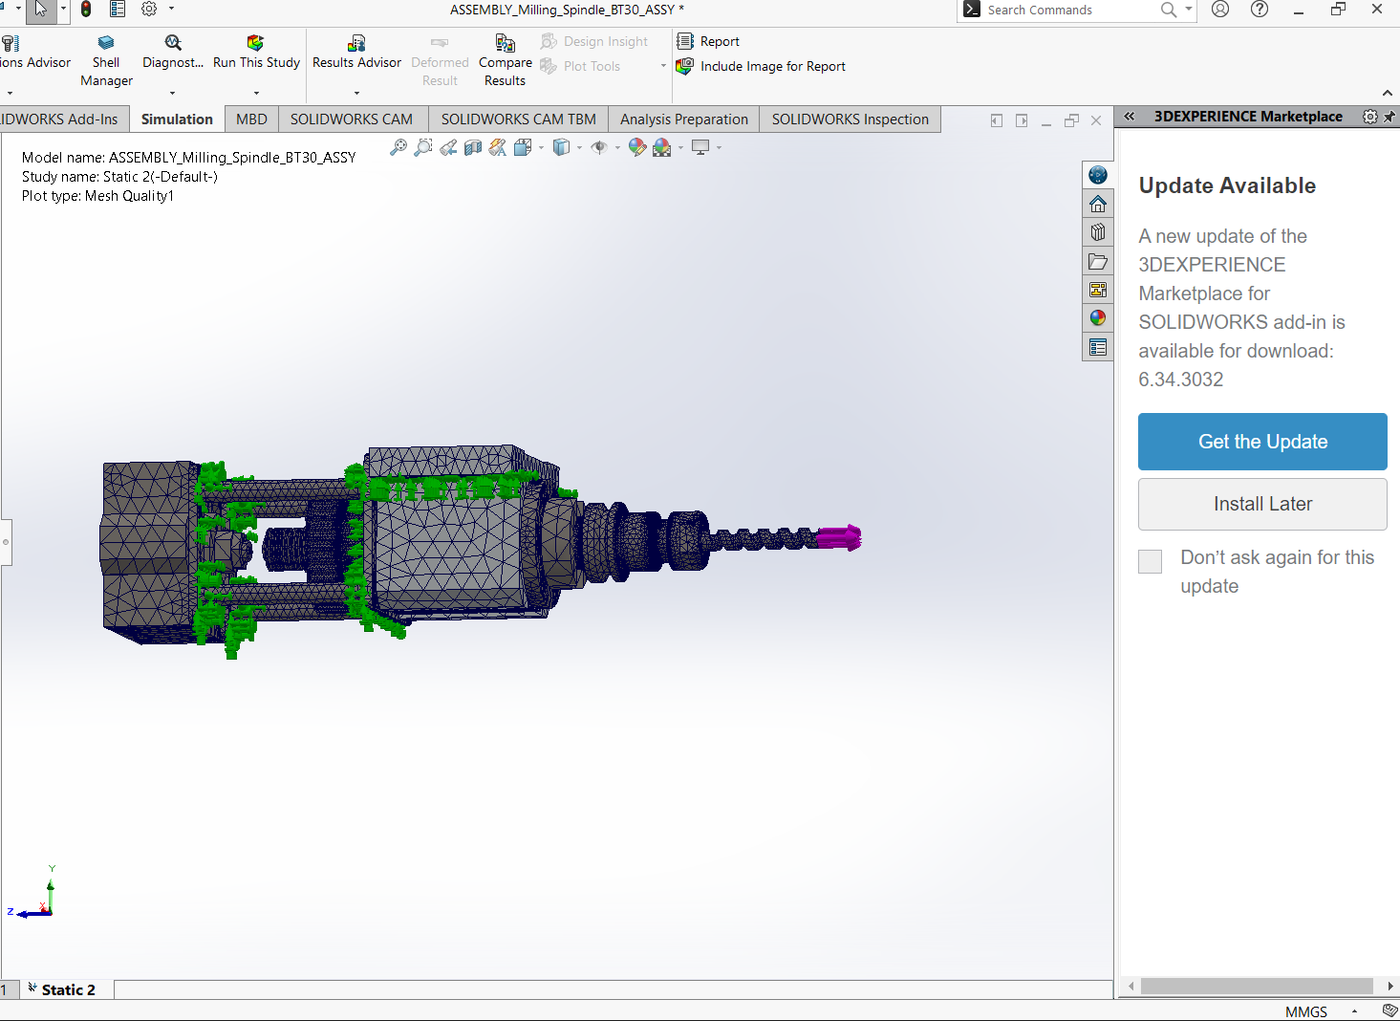
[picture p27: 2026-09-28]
Pictures/Mesh-5.png

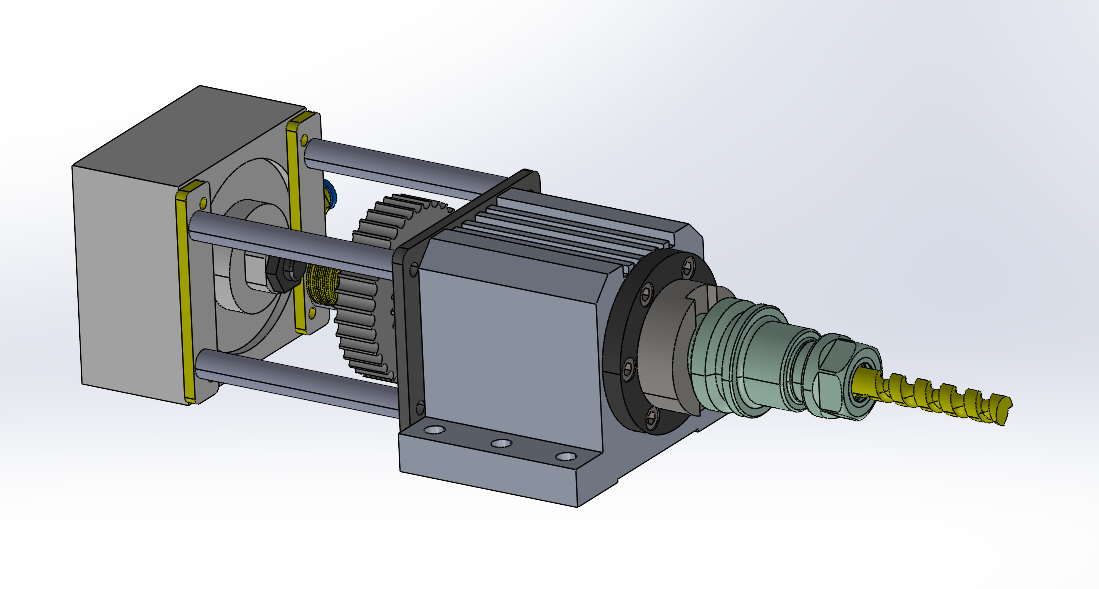
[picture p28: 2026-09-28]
Pictures/3dcad-2.png

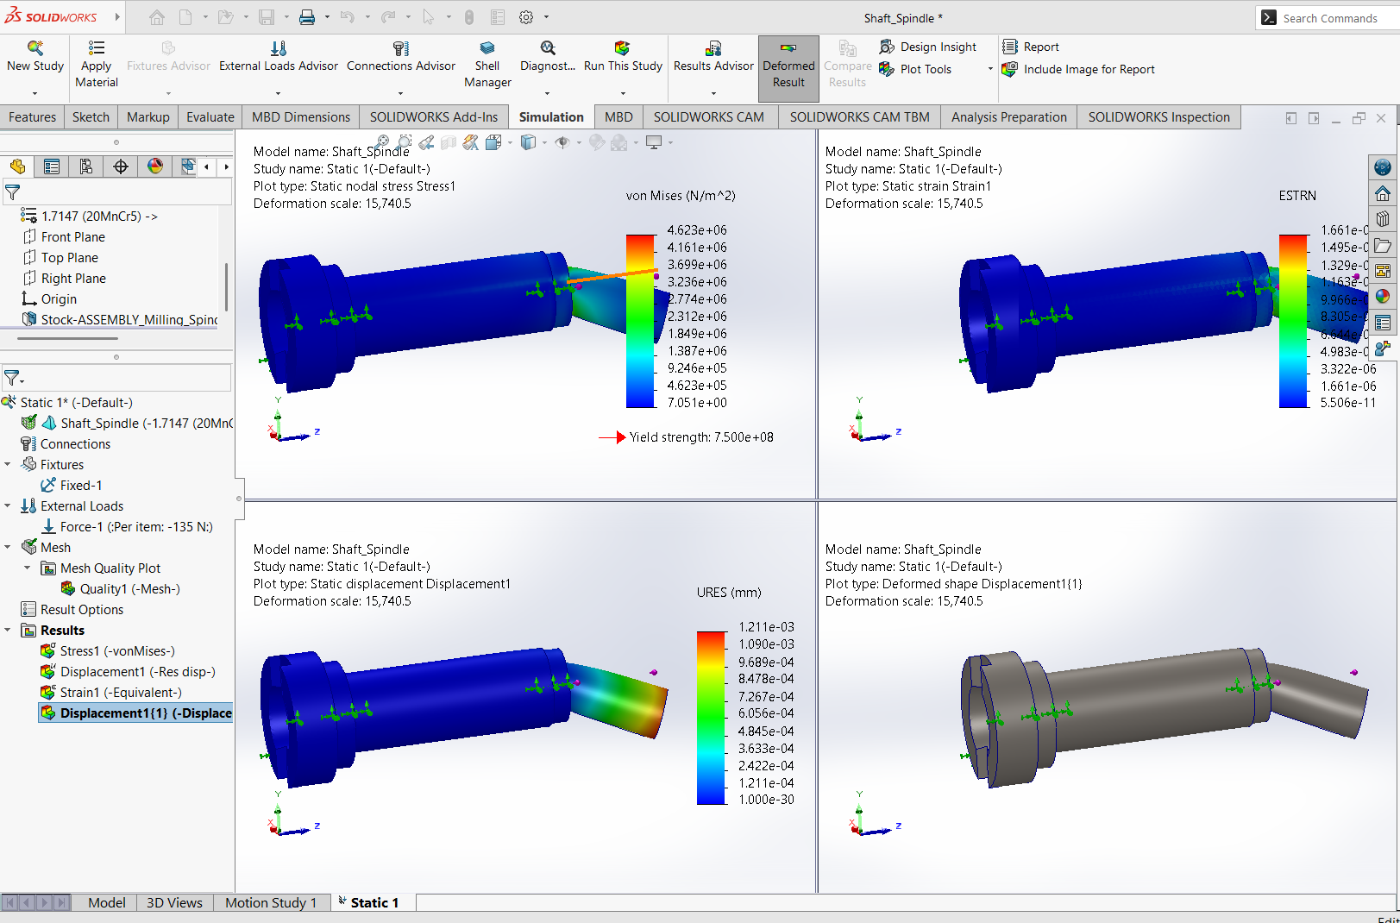
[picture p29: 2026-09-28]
Pictures/FEA-Analysis-attempt1.png

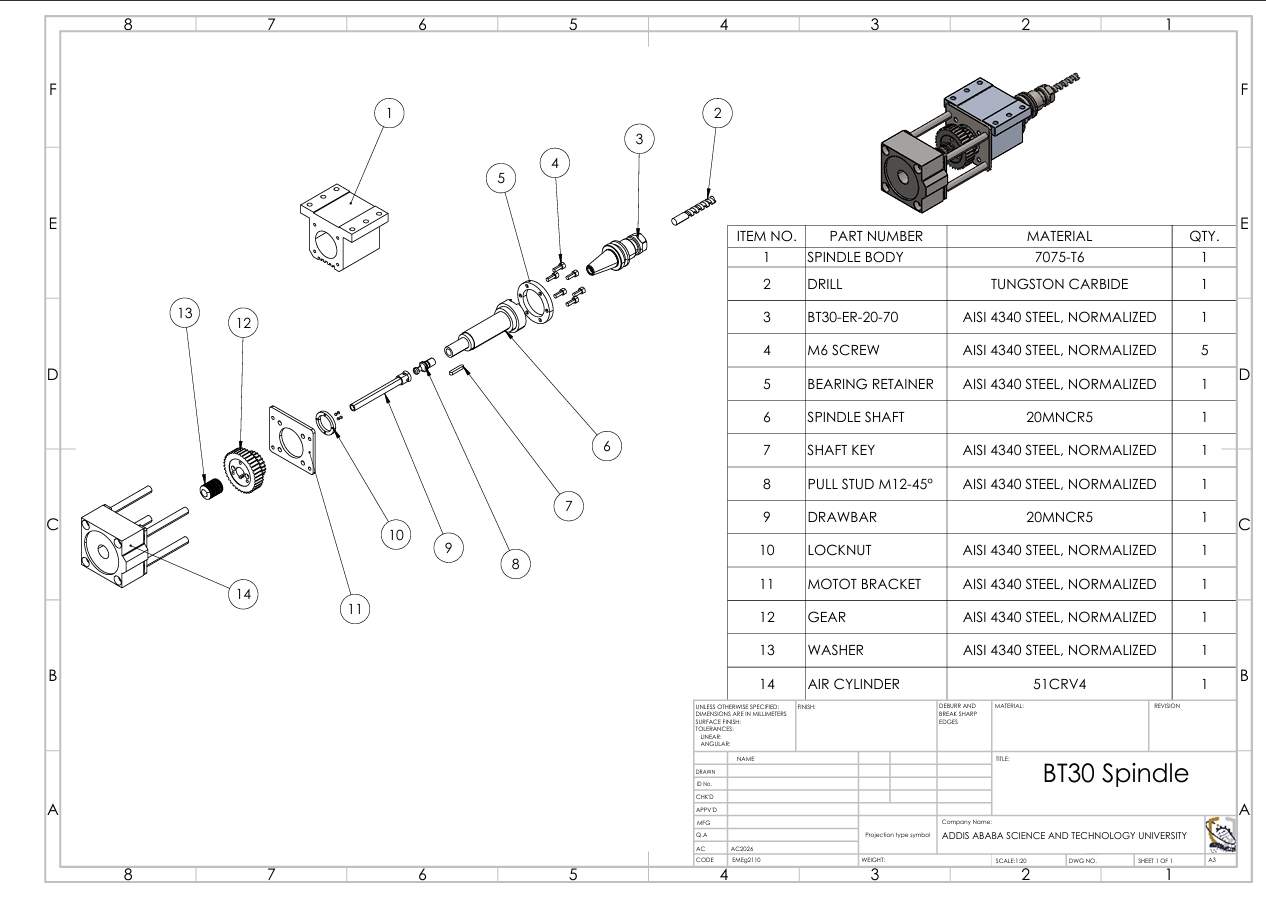
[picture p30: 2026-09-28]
Pictures/2d_drawing.png

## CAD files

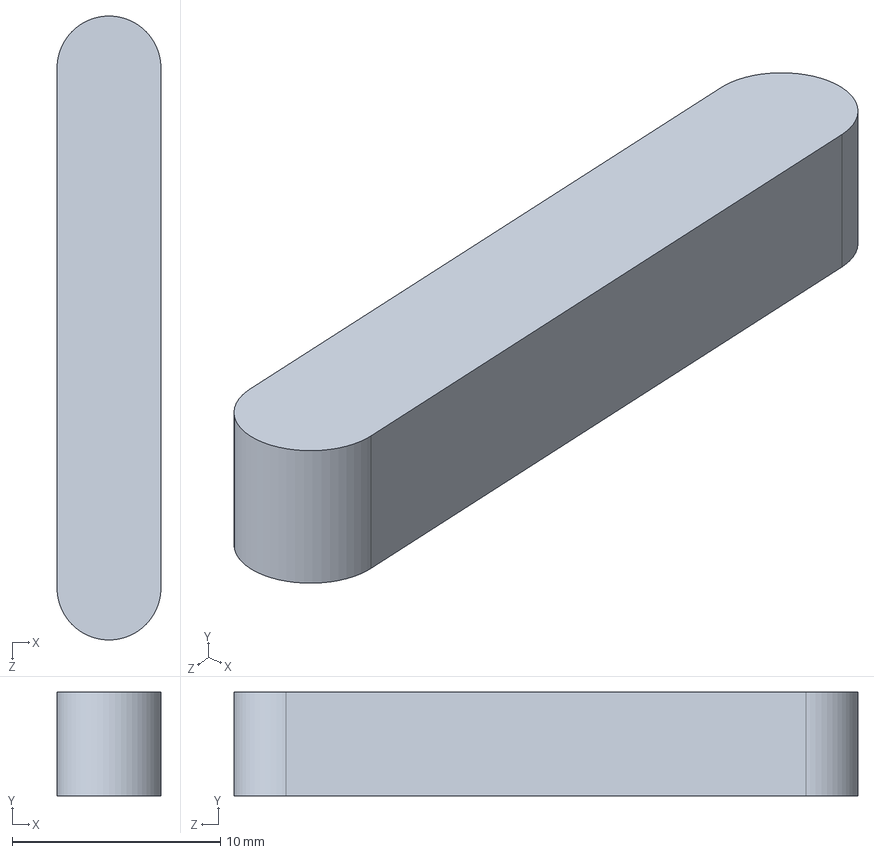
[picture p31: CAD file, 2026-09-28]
3d Models/spindle_key_5mm_x_30mm.SLDPRT
5.00 x 5.00 x 30.0 mm

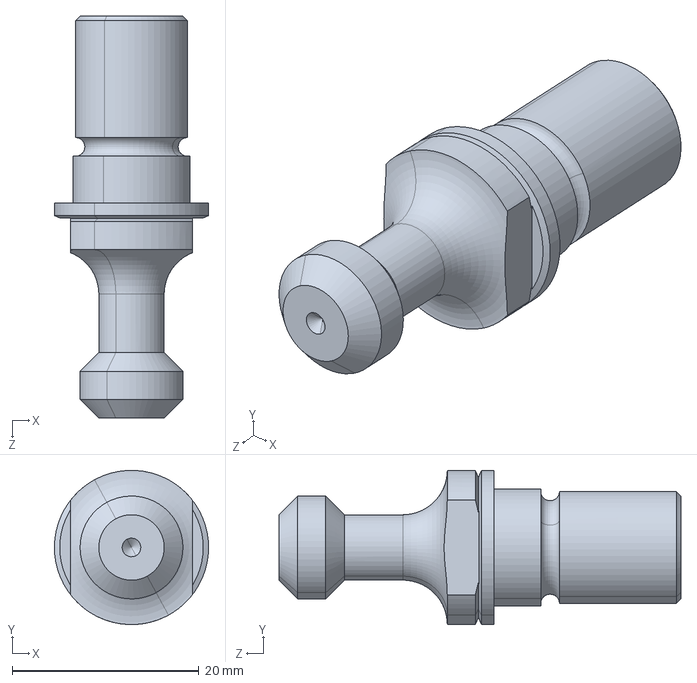
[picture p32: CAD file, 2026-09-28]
3d Models/pull_stud_m12_45.SLDPRT
16.5 x 16.5 x 43.0 mm

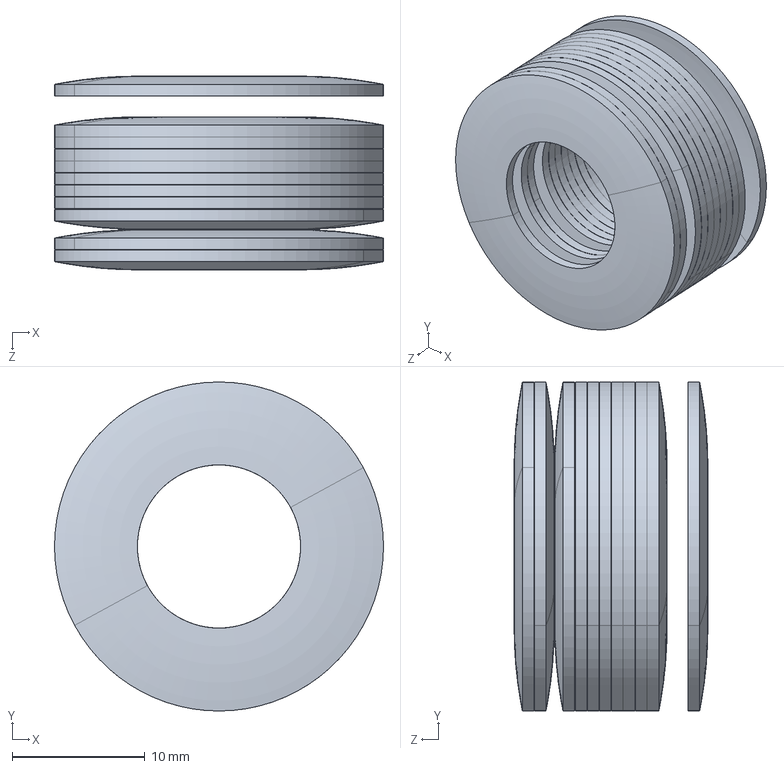
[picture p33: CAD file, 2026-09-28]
3d Models/Belleville_Washe.SLDPRT
24.8 x 24.8 x 14.6 mm

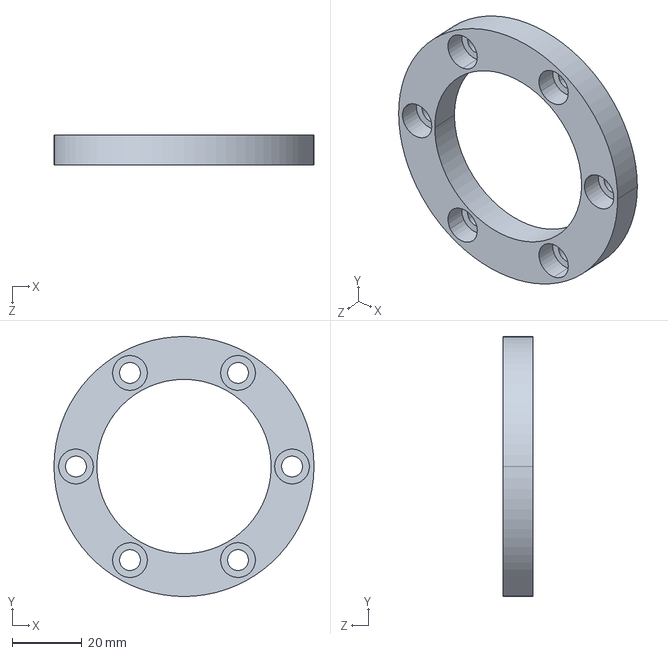
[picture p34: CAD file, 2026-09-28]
3d Models/spindle_bearing_retainer.SLDPRT
74.6 x 74.6 x 8.60 mm

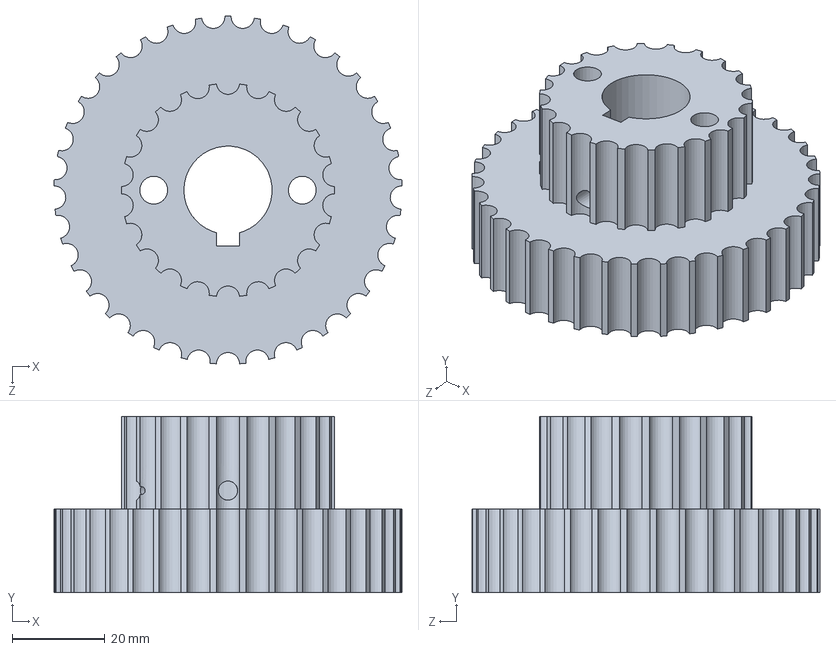
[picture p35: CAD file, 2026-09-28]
3d Models/motor_small_pulley_gear.SLDPRT
75.0 x 38.0 x 74.9 mm

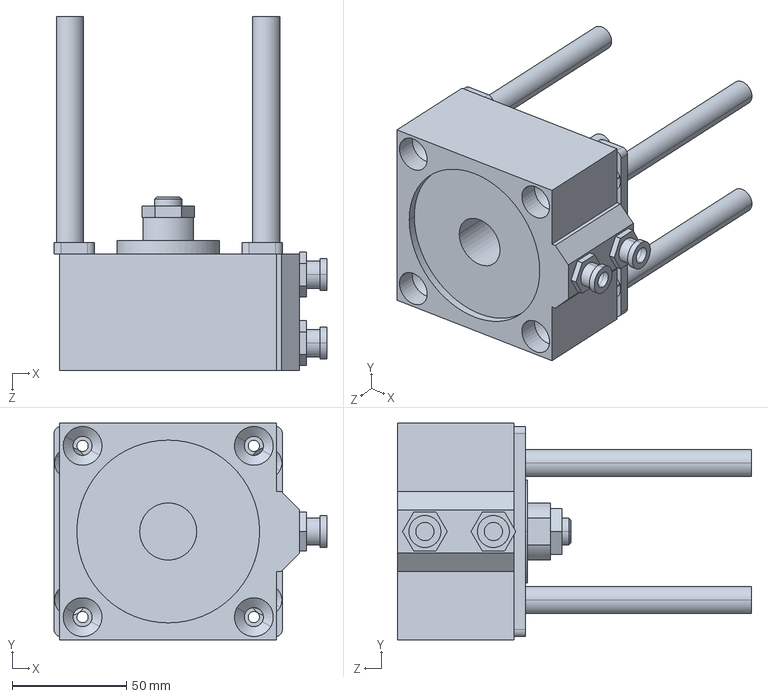
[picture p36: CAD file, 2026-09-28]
3d Models/Air_Cylinder.SLDPRT
119.5 x 95.0 x 155.0 mm

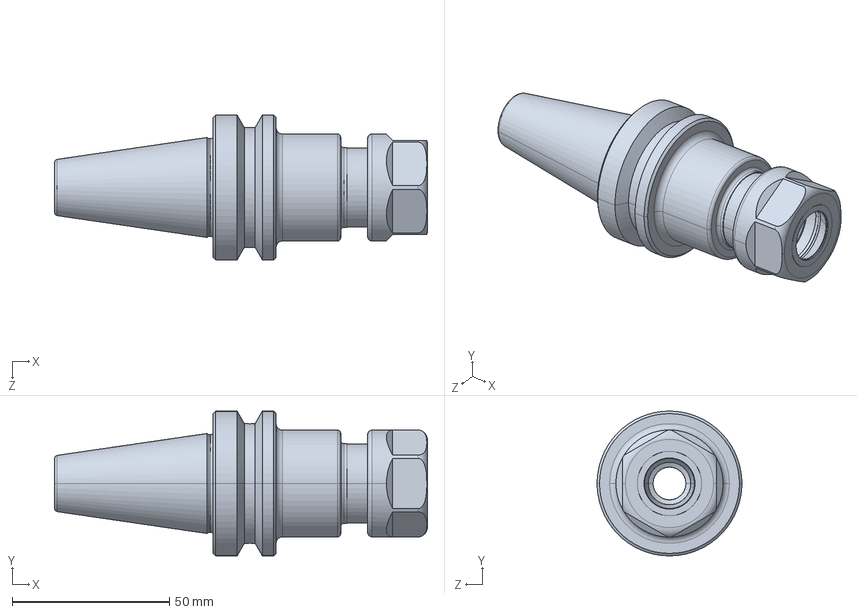
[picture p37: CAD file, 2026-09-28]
3d Models/bt30-er20-70.SLDPRT
118.4 x 46.0 x 46.0 mm

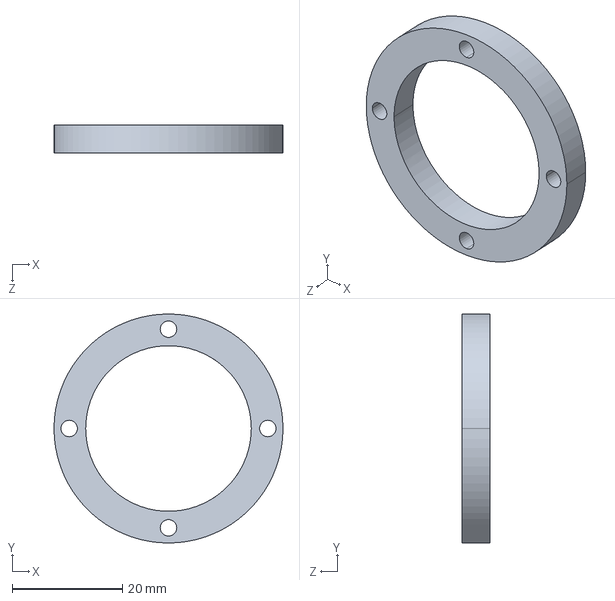
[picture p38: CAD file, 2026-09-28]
3d Models/spindle_locknut.SLDPRT
41.5 x 41.5 x 5.00 mm

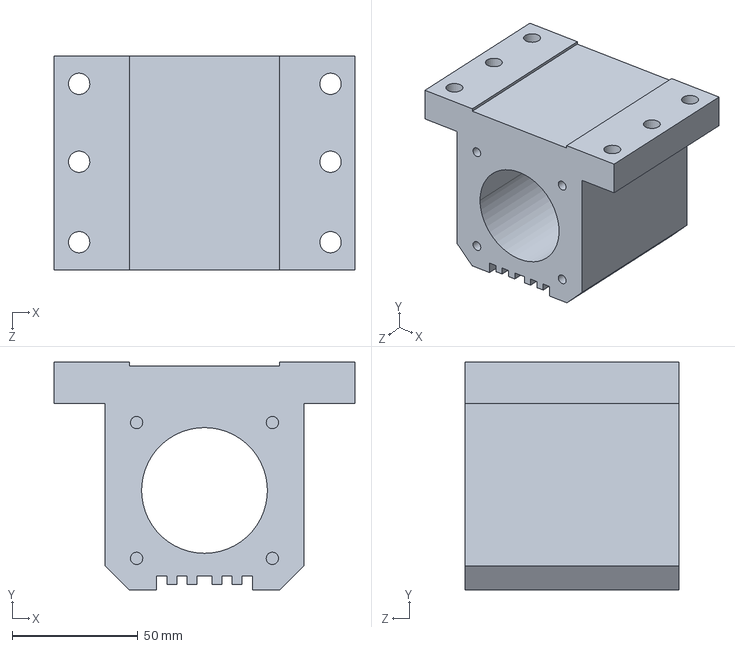
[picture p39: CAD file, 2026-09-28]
3d Models/spindle_body.SLDPRT
119.7 x 90.5 x 85.0 mm

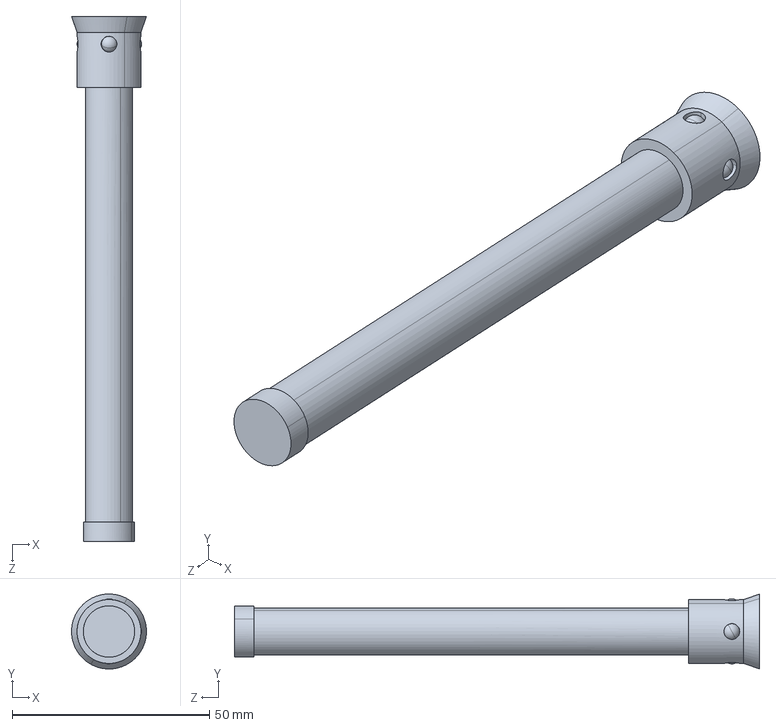
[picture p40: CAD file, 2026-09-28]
3d Models/Drawbar.SLDPRT
19.0 x 19.0 x 133.0 mm

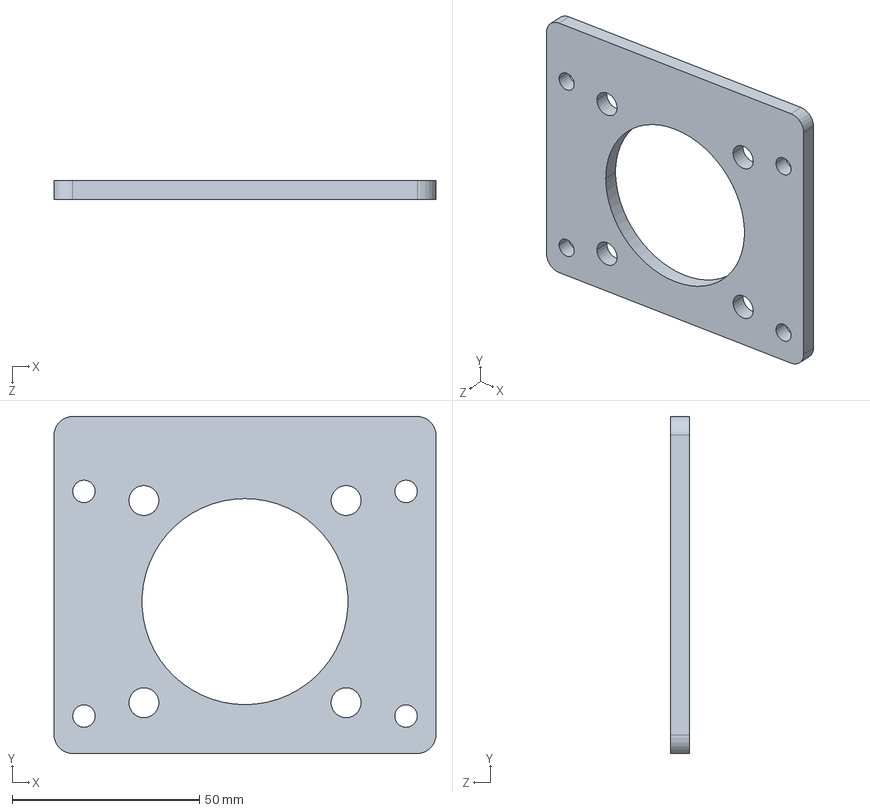
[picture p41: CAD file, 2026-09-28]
3d Models/spindle_motor_bracket.SLDPRT
102.0 x 90.0 x 5.00 mm

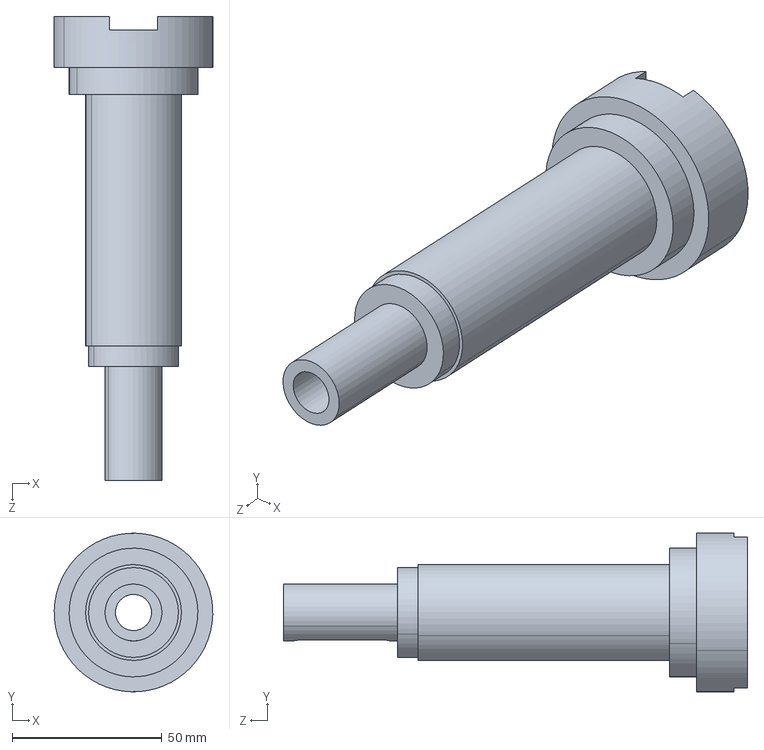
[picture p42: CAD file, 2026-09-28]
3d Models/Shaft_Spindle.SLDPRT
53.0 x 53.0 x 155.0 mm

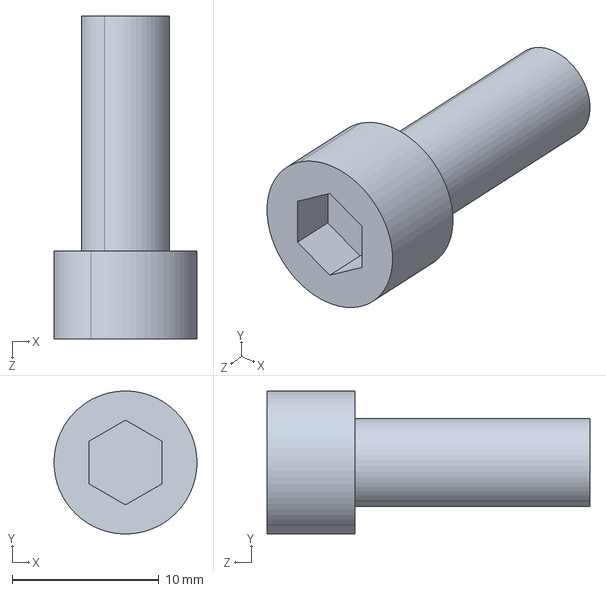
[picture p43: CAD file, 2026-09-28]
3d Models/m6x16.SLDPRT
9.74 x 9.73 x 22.0 mm

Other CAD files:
3d Models/Spindle_assembly.SLDASM

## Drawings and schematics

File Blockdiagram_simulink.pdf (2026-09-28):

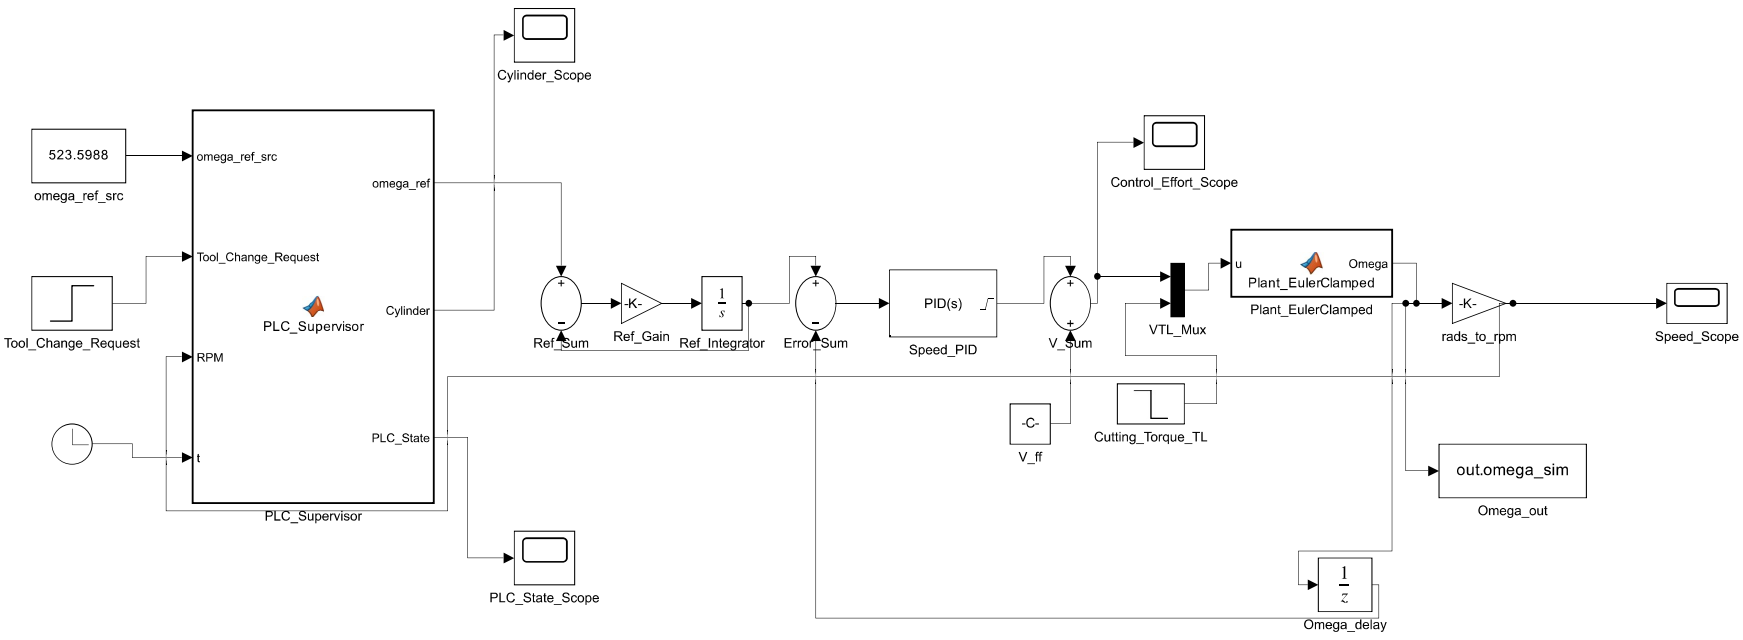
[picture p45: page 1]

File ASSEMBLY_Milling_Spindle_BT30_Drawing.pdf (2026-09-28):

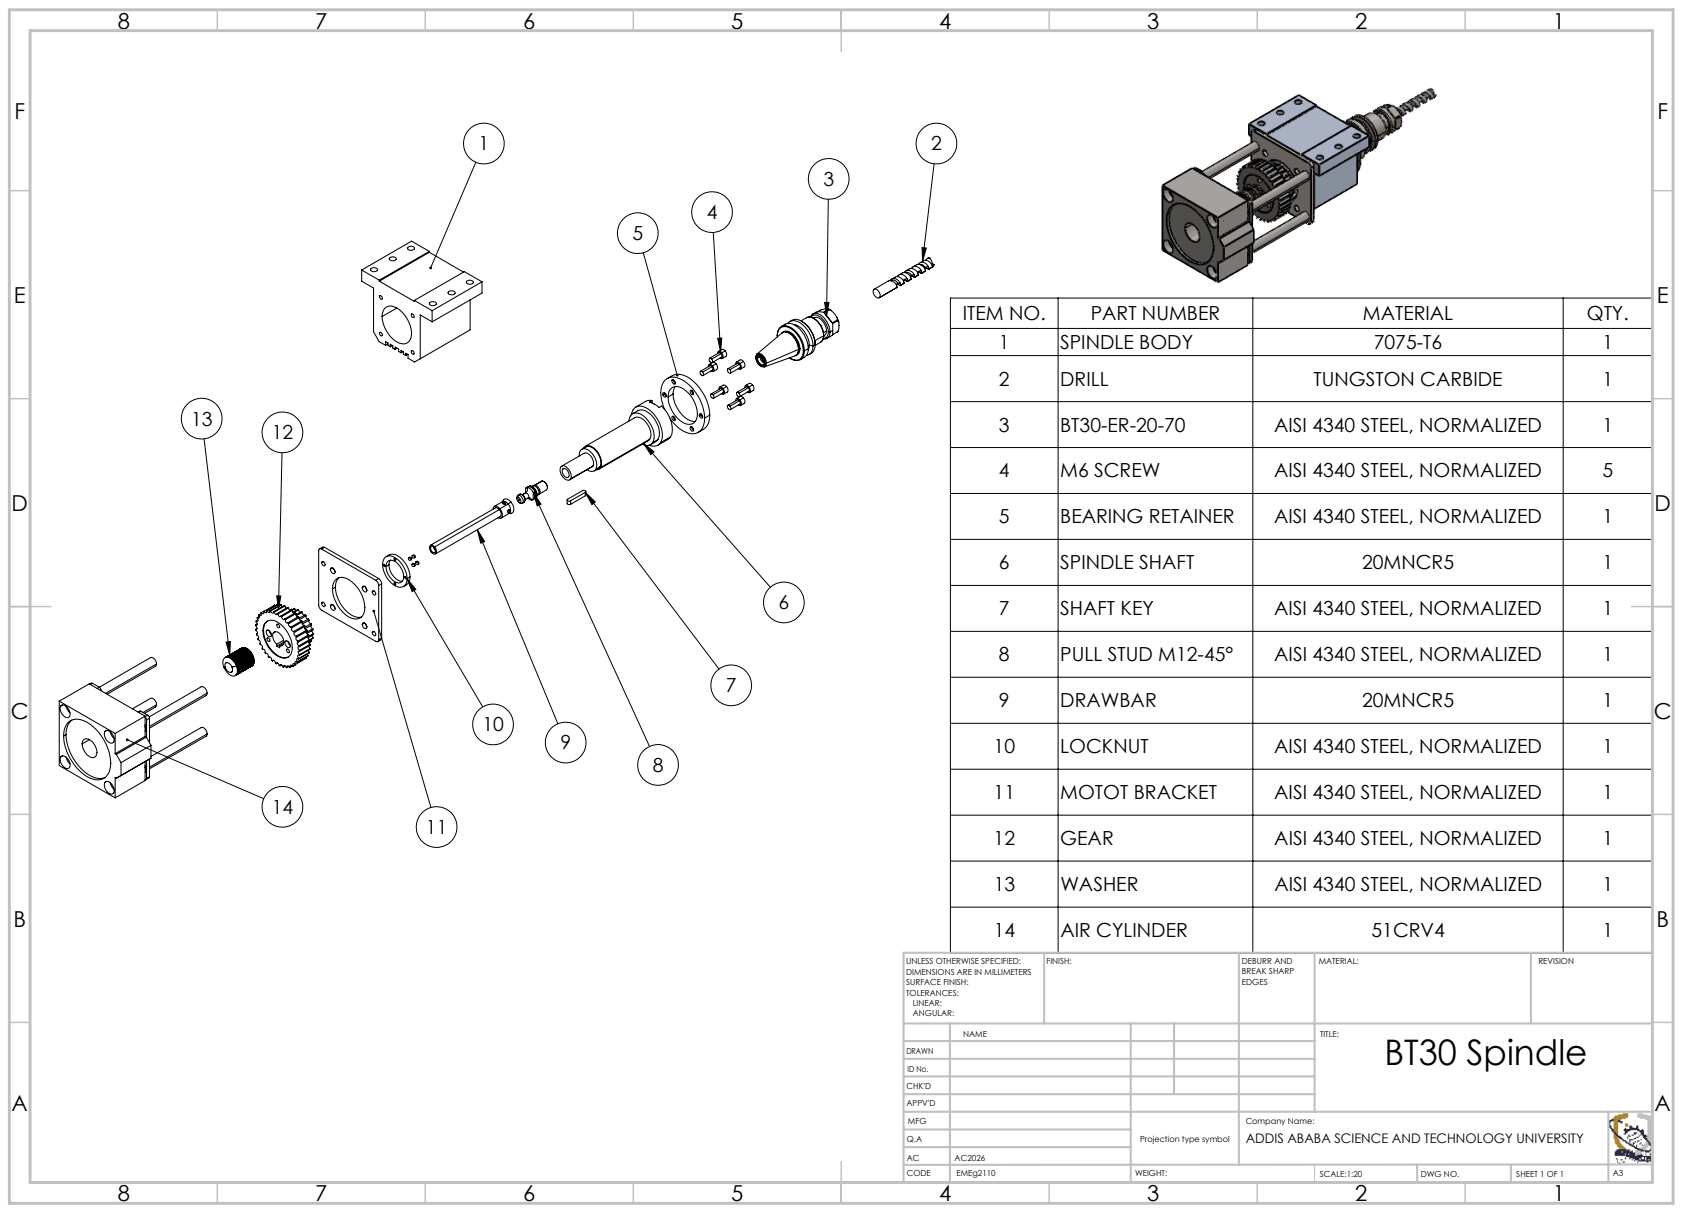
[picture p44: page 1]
GEAR; AISI 4340 STEEL, NORMALIZED

ITEM NO. | PART NUMBER | MATERIAL | QTY.
1 | SPINDLE BODY | 7075-T6 | 1
2 | DRILL | TUNGSTON CARBIDE | 1
3 | BT30-ER-20-70 | AISI 4340 STEEL, NORMALIZED | 1
4 | M6 SCREW | AISI 4340 STEEL, NORMALIZED | 5
5 | BEARING RETAINER | AISI 4340 STEEL, NORMALIZED | 1
6 | SPINDLE SHAFT | 20MNCR5 | 1
7 | SHAFT KEY | AISI 4340 STEEL, NORMALIZED | 1
8 | PULL STUD M12-45° | AISI 4340 STEEL, NORMALIZED | 1
9 | DRAWBAR | 20MNCR5 | 1
10 | LOCKNUT | AISI 4340 STEEL, NORMALIZED | 1
11 | MOTOT BRACKET | AISI 4340 STEEL, NORMALIZED | 1

13 | WASHER | AISI 4340 STEEL, NORMALIZED | 1
14 | AIR CYLINDER | 51CRV4 | 1

UNLESS OTHERWISE SPECIFIED: DIMENSIONS ARE IN MILLIMETERS SURFACE FINISH: TOLERANCES: LINEAR: ANGULAR: | FINISH: | DEBURR AND BREAK SHARP EDGES | MATERIAL: | REVISION

NAME | | | | TITLE: BT30 Spindle
ID No. DRAWN

CHK'D
APPV'D
MFG | | Projection type symbol | Company Name: ADDIS ABABA SCIENCE AND TECHNOLOGY UNIVERSITY
Q.A
AC | AC2026
CODE | EMEg2110 | WEIGHT: | SCALE:1:20 | DWG NO. | SHEET 1 OF 1 | A3
